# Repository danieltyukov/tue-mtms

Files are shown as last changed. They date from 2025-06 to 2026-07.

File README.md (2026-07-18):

<p align="center">
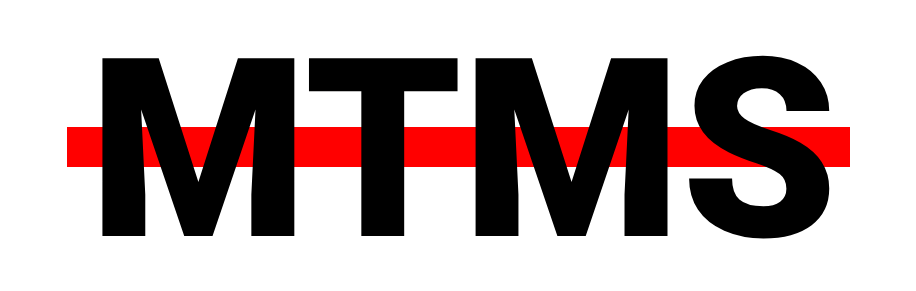
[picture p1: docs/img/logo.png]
  
</p>

<p align="center">
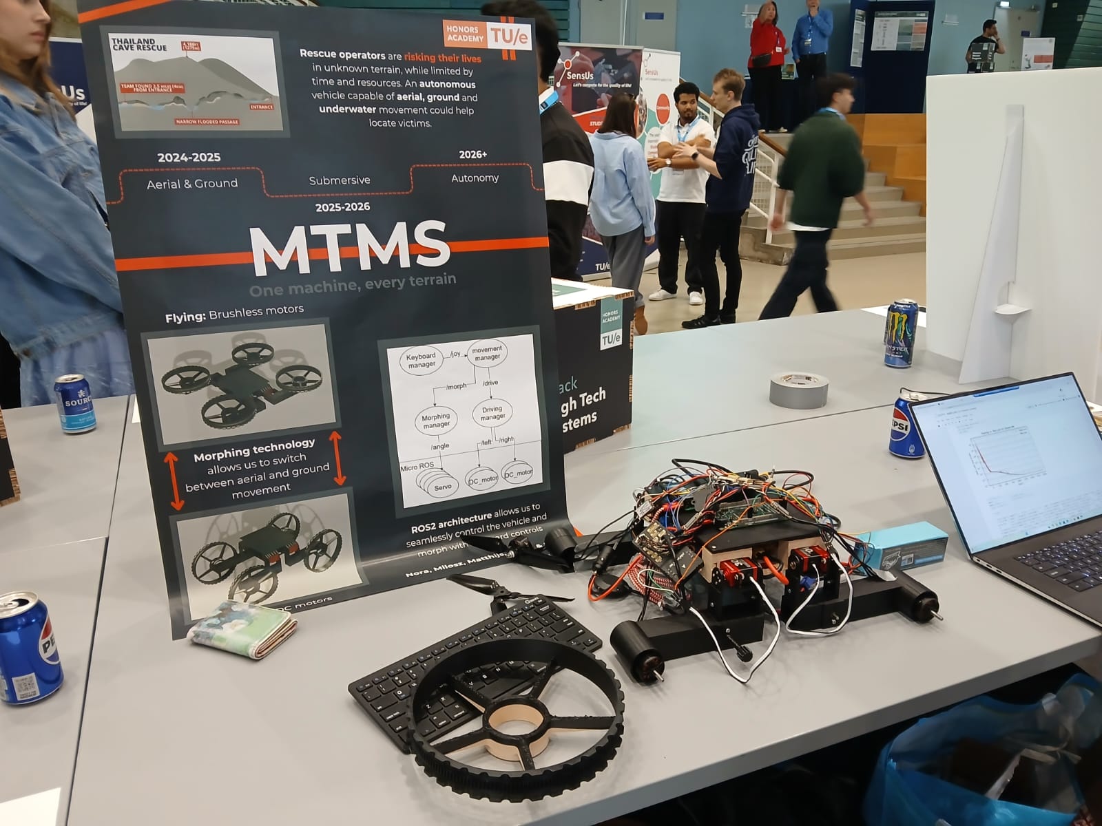
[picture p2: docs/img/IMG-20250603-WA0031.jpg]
  
</p>

# Multi-Terrain Mobility System (MTMS)

MTMS is a land and air convertible robot built for the TU/e Honors Academy High Tech Systems track (Year 2, 2024-2025). The robot carries four legs, each holding a combined wheel and propeller. It drives on the ground like a rover, then physically rotates each leg by 90 degrees to point the propellers upward and take off as a quadcopter. The long-term motivation is a rescue vehicle that can reach victims across terrain that a single ground or aerial vehicle cannot cover on its own.

Over the year the team designed and built a working prototype: the mechanical chassis and morphing mechanism, a custom power distribution board, and a ROS 2 software stack that lets an operator drive the robot, trigger the transformation, and fly it from a single keyboard.

## Prototype

The mechanical design centers on a stack of plates that house the battery, power distribution, and compute, with four legs that each carry a wheel-propeller assembly. The two states below are the same robot: wheels down for driving, and rotated for flight.

<p align="center">
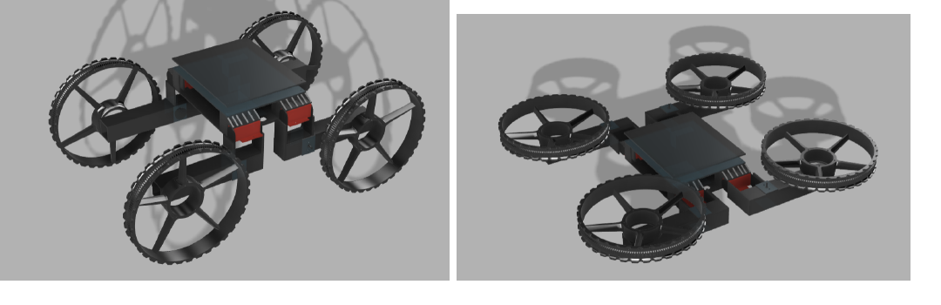
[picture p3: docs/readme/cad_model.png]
  
</p>

## Software architecture

The control software runs on ROS 2 (Jazzy) on a Raspberry Pi 5, with a micro-ROS firmware layer on an Arduino Due that drives the motors and servos. The nodes form a small pipeline from keyboard input down to hardware:

- `keyboard` and `keyboard_to_joy` capture keypresses through SDL and turn them into a `sensor_msgs/Joy` message. W/S and A/D map to the throttle and steering axes, Space is a boost button, and Q requests a mode change.
- `movement_manager` subscribes to `/joy` and routes input to either the `/drive` or `/fly` topic depending on the current mode. Pressing Q sends a `MorphAction` goal, with debouncing so a single press does not trigger repeated transitions.
- `drive_manager` converts the joystick axes into tank-style left and right motor commands and publishes them as PWM values on `/drive_left` and `/drive_right`.
- `morph_manager` is the `MorphAction` server. It sweeps the leg servos between the drive and fly positions in small steps through a `SetAngle` service and reports transition progress as feedback.
- The Arduino Due firmware (`code/Servo_sweeping`, PlatformIO) is a micro-ROS node. It subscribes to `/drive_left` and `/drive_right` to drive four DC motors and hosts the `servo_service` that rotates the four leg servos.

`movement_msgs` defines the custom `MorphAction` action and `SetAngle` service that tie these nodes together.

## Repository structure

```
code/ros_ws/            ROS 2 workspace
  src/movement_manager/  movement, drive and morph manager nodes
  src/movement_msgs/     MorphAction action and SetAngle service
  src/keyboard_controls/ keyboard capture and keyboard-to-joy conversion
  src/launch_mtms/       top-level launch files
code/Servo_sweeping/    micro-ROS firmware for the Arduino Due (PlatformIO)
code/startup.sh         boot script, paired with start_robot.service
BMS_schematic/          battery management KiCad project
mechanical/             CAD designs and STL exports
docs/                   logo, Gantt planning, report figures
Honors_report_2025.pdf  full project report
```

## Running it

Build the workspace and launch the stack on the robot:

```bash
cd code/ros_ws
colcon build
source install/setup.bash

# start the micro-ROS agent so the Arduino Due can join the ROS 2 graph
ros2 run micro_ros_agent micro_ros_agent serial --dev /dev/ttyACM0

# start the managers and keyboard control
ros2 launch launch_mtms launch_mtms_launch.py
```

The keyboard node opens a small window that must stay focused to receive input. On the robot itself the same flow is wired into `code/startup.sh` and a `start_robot.service` unit so everything comes up on boot.

## Hardware

- Raspberry Pi 5 as the main computer running the ROS 2 stack
- Arduino Due running the micro-ROS firmware for motor and servo control
- Pixhawk 6C flight controller for the aerial mode
- Brushless motors and propellers for flight, DC motors and servos for driving and morphing
- 22.2V 4000mAh 6S LiPo battery
- Custom power distribution PCB (KiCad) with XT60 input and multiple XT30 outputs

## Technologies

ROS 2 Jazzy, Python, micro-ROS, C++ (Arduino / PlatformIO), KiCad, CAD.

## Planning

Progress was tracked with Gantt charts that were revised as component deliveries and priorities shifted. The full schedule and milestones are in [docs/gantt_chart.svg](docs/gantt_chart.svg).

## Contributors

Team MTMS

- Alex Ceano Vivas i Camacho (coach, Honors High Tech Systems track)
- Nora Balje
- Daniel Tyukov
- Ismail Hassaballa
- Milosz Janewski
- Matthijs Smulders

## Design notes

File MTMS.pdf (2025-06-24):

## MTMS: Multi-Terrain Mobility Systems

## Project proposal

High tech systems

Nora Balje´
Milosz Janewski
Daniel Tyukov
Matthijs Smulders
Ismail Hassaballa

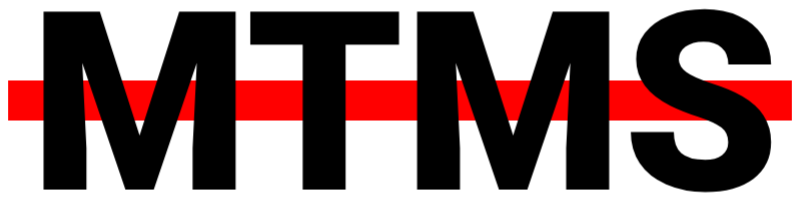
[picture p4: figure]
Date: June 24, 2025

High tech systems: MTMS Project Proposal

## Contents

Abstract | 3
Description | 3
Workpackages and timeline | 4
Impact | 5
Demo Day package | 5
Equipment and Budget | 6

## Abstract

The MTMS (Multi-Terrain Mobility Systems) project proposal outlines the potential development of a multi-terrain robot capable of transitioning between ground, aerial and water based modes. Existing research, combining 2 out of 3 of the previously mentioned modes, showcases that creating such a system would be possible, however combining all 3 has yet to be done. The primary objective for the coming year of the project is to build a functional prototype running on Robot Operating System 2 with integrated wheels and rotors, enabling manual control and basic navigation for ground and aerial based modes. Over the course of the year, the focus will be on hardware assembly, system integration, and testing of the robot’s hybrid mobility capabilities. In the following years, further development will focus on integrating the water based mode, creating a fully autonomous navigation functionality, obstacle avoidance, and terrain mapping. The overall budget for this initial phase is approximately two thousand six hundred euros.

## Description

For our project, we want to build a Multi-terrain mobility system, where we will start with ground and aerial mobility for this current year. Water based movement and autonomous control will follow in future years. The ground based movement will take the form of a remote control car, then it will be able to fold its wheels below its body to morph into a type of drone, allowing for aerial movement. We are going to depict how we will design such a system, what software and hardware we will need, what the timeline for building said system will be and how we can extend upon it in future years.

Design

We plan to take most of our inspiration from the M4 robot built by CalTech [1] and the Flying STAR built by Nir Meiri and David Zarrouk [2]. Both these robots have propellors and wheels on the end of their arms and rely on moving these arms down to move between mode of transportation. We want to implement a similar approach, and challenge ourselves to include a joint in the arms for extra ground and air mobility with morphing capabilities. We can build upon research for wheeled quadrupedal such as Bjelonic, M. et al’s research [3].

Software

We chose to use ROS2 (Robot operating System 2) software as it provides a robust, widely adopted framework for robotic development, with extensive community support. Additionally, we opted for ROS2 instead of ROS1, due to improved architecture and speed of the framework. Hence, compatibility with ROS2 was a main factor taken into account when choosing our hardware components.

Hardware

Because we are designing a robot with non-standard functionality, obtaining parts off the shelf can be difficult, particularly for connecting all the electronics together. This is why we plan to 3D print many parts ourselves, which provides the flexibility needed for our design specifications. Within the team, we are currently discussing the use of Fusion 360 or Onshape for designing these parts, as both programs offer similar tools suited to our requirements.

However, this approach presents challenges for future multi-mobility in water. While 3D printing offers quick prototyping, the materials (PLA) are not reliably waterproof. Additionally, isolating electronics from water effectively and ensuring buoyancy requires specific materials and design adjustments. While we are not focusing on this aspect in the current project phase, our long-term goal includes research in waterproofing, buoyancy, and electronics protection. This foundational research aims to eventually make the system rainproof and eventually submersible.

Flight Controller and Power Electronics

For the flight controller, we plan to use the Pixhawk 6C, due to its many capabilities and native ROS2 compatibility. The PX4 provides us with a well-supported platform for handling aerial navigation, allowing integration with the robot’s multiple sensors and actuators. We can use tools like Ardupilot which enables us to test and fine-tune our system across different flight modes.

On the power electronics side, we’re assembling a power distribution system internally inside the system. This includes a 4S 4000Mah battery with step-down buck converters to maintain specific voltage requirements across the system. To keep the mechanical design of the system adaptable, we’ll incorporate a basic PCB with inputs and outputs for wire connections (a basic power distribution board with outsourced components). This will centralizes wiring but also simplifies adjustments to the setup.

To track power usage, we will integrate a current and voltage sensor within the power electronics system. This will allow us to monitor consumption in real-time.

While autonomy is limited, this initial phase of the project is focused primarily on predefined movement sequences in ROS2. We aim to research the potential for greater autonomy by using sensor data for future, including obstacle avoidance via infrared sensors. Currently, the system will be controlled manually, with specific automatic reactions.

Component | Quantity | Voltage (V) | Current (A) | Power (W)
Hip Servos Wheel Motors Propeller ESCs Main Controller Flight Controller | 8 4 4 1 1 | 7.4 12 12 5 5 | 3.0 1.5 4.0 0.5 0.4 | 177.6 72.0 192.0 2.5 2.0
Total | | | | 446.1

Table 1: Estimated Power Consumption of Key Components

Future Development

As mentioned the focus for this year will be on ground and aerial control, however, eventually we wish to create an all-terrain vehicle that can survive any circumstances. So one clear future development would be implementing mobility in the water. After that, we want to slowly progress to autonomy within the robot, such that even without human control it can reach its destination. This would obviously require advanced navigation, obstacle avoidance, and autonomous mission planning, but also terrain detection and knowing when to morph, all powered by ROS2 algorithms. We will discuss how the current sensor data and manual control operations serve as the foundation for the future autonomous capabilities of the robot.

## Workpackages and timeline

Nov | Dec | Jan | Feb | Mar | Apr | May | Jun
Midterm Review (Feb 4) | Final Demo (Jun 3)
Structure & Design | ROS Development

Module Testing
Integration Testing

This timeline outlines the planned phases and milestones for the MTMS project. After receiving approval for our plan on November 15, we plan to order all necessary components, which according to their checked lead times should arrive by the end of November. Having acquired all components we can dedicate December to assembling the robot, including designing and 3D printing custom parts as needed. From January to April, we’ll work on ROS2 development and control implementation. Where January the focus will be on ground based control, February the focus will be on morphing and in March the focus will be on Aerial control. In April and May, individual modules will undergo testing, followed by full integration testing by mid-May. Key milestones include the midterm review on February 4 and the final demonstration on June 3.

## Impact

Our MTMS is set to redefine exploration of unknown or hazardous terrains. Unlike current solutions that are limited to only one or two specific terrain types, such as ground and aerial or aerial and water, the end goal for our MTMS is that it can navigate and adapt to three terrain types: ground, aerial and water. This versatility could revolutionize exploration in locations where traditional methods are ineffective or unsafe, such as disaster sites, alien landscapes, or varied terrains that demand adaptability.
The impact of our system lies in its accessibility and efficiency, especially compared to high-budget, long-term projects like Caltech’s M4 [1]. By prioritizing a leaner budget and a short development timeline, MTMS could make advanced terrain mobility more achievable for a wider range of applications. We will also focus on a smaller scale testing environment by developing the system in ROS2, which enhances the research value. While water traversal is outside this year’s scope, we’ll start researching the possibilities for future development. Ultimately, our project could open up the road to more versatile multi-terrain traversal which is more financial accessible and contributes to further research in this field.

## Demo Day package

On the final presentation day, we will demonstrate the multi-terrain robot prototype that we developed over the course of the year. The goal of this demo is to showcase the robot’s dual mobility capabilities, transitioning smoothly between ground and aerial modes, and moving in each mode, while being manually controlled via a ROS2 interface.

Key Objectives for Demo day

- Manual Control via ROS2 Interface: We will demonstrate the robot’s ability to be controlled manually through a ROS2-based interface. Attendees will be able to see how we utilize ROS2 to operate both the wheeled and rotor-based mobility systems, highlighting the integration between hardware and software.
- Ground Mobility: The robot’s wheeled mobility system will be showcased by navigating through an obstacle course, demonstrating its ability to handle different types of terrain, such as uneven surfaces and ramps.
- Aerial Mobility: Following the ground demonstration, we will showcase how the robot switches to its aerial mode. However as it is not feasible to fly the robot during the demo day itself this skill will be presented in a pre-recorded video. Here we will showcase stable flight control.

Midterm Demo Day

On the midterm demo day we wish to showcase the hardware design of the robot and its ability to move on the ground. We aim to showcase our progress in both the hardware and software component by presenting our moving vehicle. The complex movements such as morphing and flying will not be showcased here as we do not aim to have these implemented by the midterm presentation.

## Equipment and Budget

The costs of all necessary hardware components for this project will come to a total of C2594.65. The breakdown of these costs is depicted in the table below. Alongside these hardware costs there are theoretical labor costs that come along with creating such a project. To realize this project we will need a team of 5 people, who will work on this project approximately 6 hours a week for the next 33 weeks. Assuming a pay of C15 an hour this will bring in an additional cost of C14850 in labor. However, due to the nature of our project we will not count labor costs
towards the final budget.
Component | Description | Price | Supplier | Delivery time
Main Computer | UP Xtreme i14 | C967 | Up squared/Mouser | Email inquiry
Flight controller | Pixhawk 6C | C220 | Holybro | 1 week
Secondary Computer | Raspberry Pi 5 | C94.90 | reichelt | 3 days
Microcontroller | Raspberry Pi pico | C8.5 | Tinytronics | 3 days
Lidar sensor | For scanning area | C124 | Generation robots | 3 days
GPS Module | M10 | C80 | Holybro | 1 week
Telemetry Radio | 433MHz | C100 | Holybro | 1 week
3x Batteries | To power the system | C290.37 | Racedayquads | 3 days
4x wheel | To enable driving | C28 | Amazon | 3 days
4x 3MR Series - 3-Blade 8x4.1 Propeller | To enable flight | C20 | masterairscrew | 2 weeks
4x DC motor | To move the wheels | C74,04 | Mouser Electronics | 5 days
2x motor driver board | to control the motors | C33 | Tiny tronics | 1 day
4x EMAX Bullet Series 35A 3-6S ESC | To control and adjust power for the
| brushless motors | C80 | Emax | 1 week
4x Pro Series 2812 Brushless Motor | To move the propellors | C120 | Emax | 1 week
8x Servo (180°) | To enable the 2 joints per leg | C176 | TinyTronics | 1 day
2x Mini 12V 4”Stroke Electric Linear Actuator | To enable shifting between flight and
| driving | C60 | Amazon | 1 week
3x Camera’s (120°) | To enable the person in control to
| see around vehicle | C91,28 | Adafruit | 4 days
2 kg PLA filament | For 3D prining custom parts for as- sembly and frame | C59,80 | TinyTronics | 1 day
Miscellaneous | Additional wiring, connectors and assembly parts | C90 | TinyTronics, etc | Depends on parts
Total | - | C2720.00 | - | -

Table 2: Component and Budget List for Multi-Terrain Robot

## References

[1] Sihite, E., Kalantari, A., Nemovi, R. et al. Multi-Modal Mobility Morphobot (M4) with appendage repurposing for locomotion plasticity enhancement. Nat Commun 14, 3323 (2023). https://doi.org/10.1038/s41467-023-39018-y
[2] N. Meiri and D. Zarrouk, Flying STAR, a Hybrid Crawling and Flying Sprawl Tuned Robot, 2019 International Conference on Robotics and Automation (ICRA), Montreal, QC, Canada, 2019, pp. 5302-5308, doi: 10.1109/I-CRA.2019.8794260.
[3] M. Bjelonic et al., Keep rollin’—whole-body motion control and planning for wheeled quadrupedal robots, IEEE Robotics and Automation Letters, vol. 4, no. 2, pp. 2116–2123, Apr. 2019. Available: https://arxiv.org/pdf/1809.03557

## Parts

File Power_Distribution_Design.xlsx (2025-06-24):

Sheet: Power Table
Component | Voltage | Current (A) | Quantity | Power Domain | Power (W) | Energy Share (Wh)
Brushless Motor + ESC | 11.1–22.2V | 60 | 4 | Primary | 1332 | 22.2
Pixhawk 6C System | 5V | 1 | 1 | Primary | 5 | 0.08333333333
Servo | 8.4V | 18.4 | 4 | Secondary | 154.56 | 2.576
RPi 5 | 5.1V | 5 | 1 | Secondary | 25.5 | 0.425
Linear Actuator | 12V | 1.2 | 2 | Secondary | 14.4 | 0.24
Arduino Due | 7–20V | 0.2 | 1 | Secondary | 4 | 0.06666666667
DC Motor | 12V | 2.8 | 4 | Secondary | 33.6 | 0.56
Lidar | 5V | 0.26 | 1 | Secondary | 1.3 | 0.02166666667

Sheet: Summary
Total Battery Voltage (V) | Battery Capacity (Ah) | Battery Energy (Wh) | Total Power Draw (W) | Primary System Power (W) | Secondary System Power (W)
22.2 | 4 | 88.8 | 1570.36 | 1337 | 233.36

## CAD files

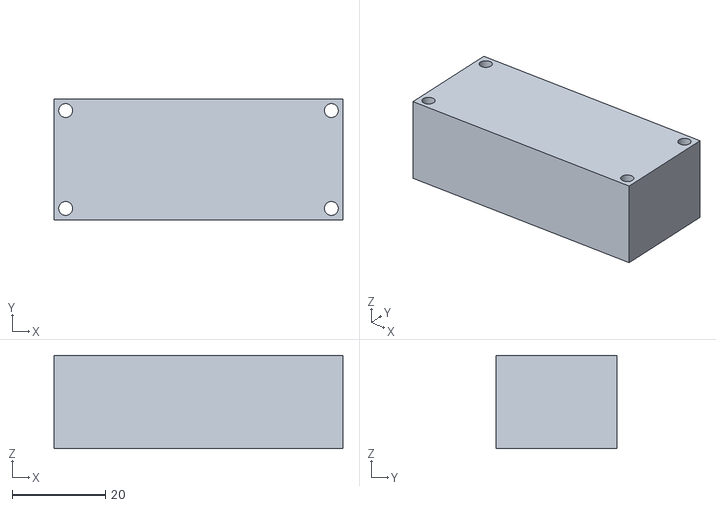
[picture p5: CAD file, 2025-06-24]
mechanical/CAD_designs/Buck+converter.stl
62.0 x 26.0 x 20.0

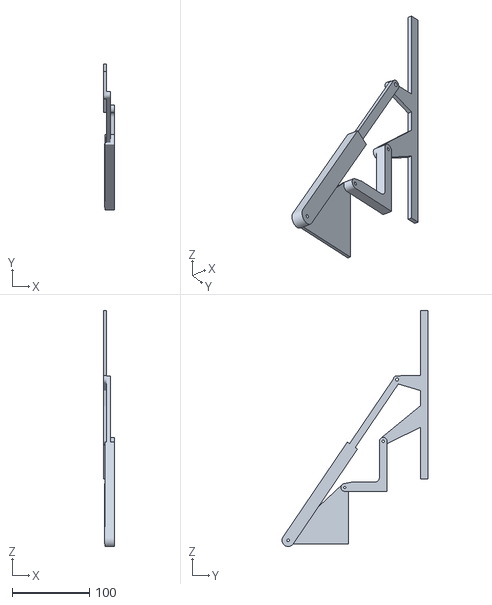
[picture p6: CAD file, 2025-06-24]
mechanical/MTMS-Transform-Mechanism-V1.stl
14.0 x 189.5 x 306.4

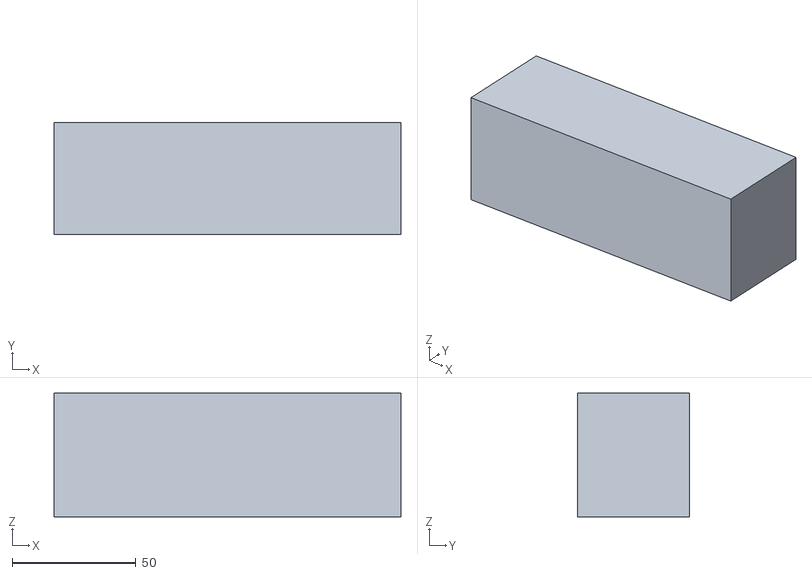
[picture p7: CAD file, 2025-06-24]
mechanical/CAD_designs/LiPo+(approximatedd+size).stl
140.0 x 45.0 x 50.0

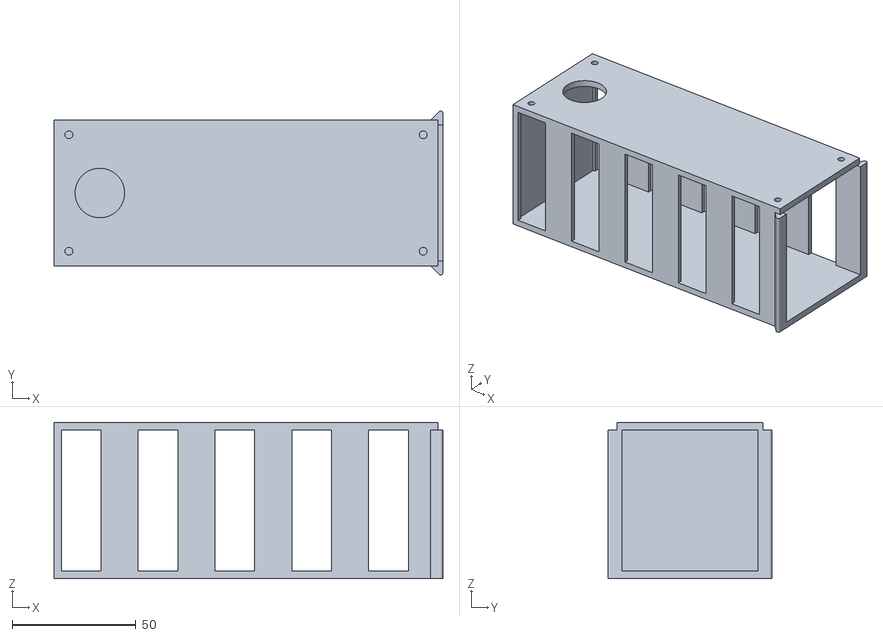
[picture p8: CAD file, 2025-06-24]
mechanical/CAD_designs/Battery+cover (1).stl
157.0 x 66.2 x 63.0

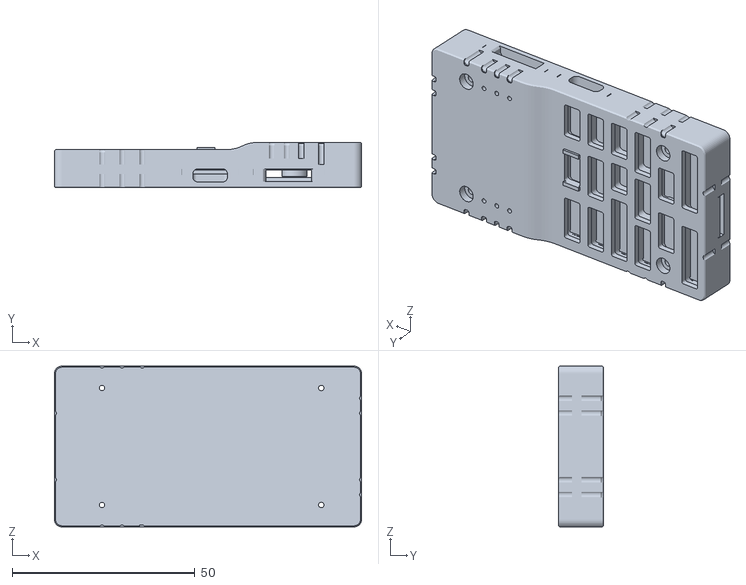
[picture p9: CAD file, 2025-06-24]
mechanical/CAD_designs/Pixhawk6C-3D-CAD.stl
84.0 x 12.4 x 44.0

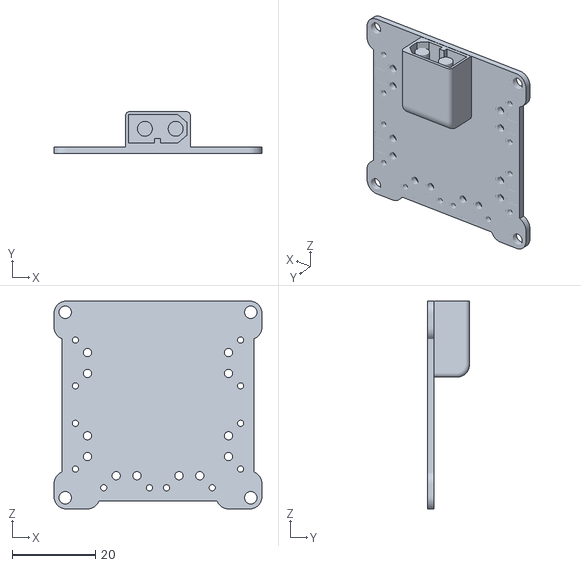
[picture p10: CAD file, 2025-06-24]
mechanical/CAD_designs/Power+distribution.stl
50.0 x 10.1 x 50.0

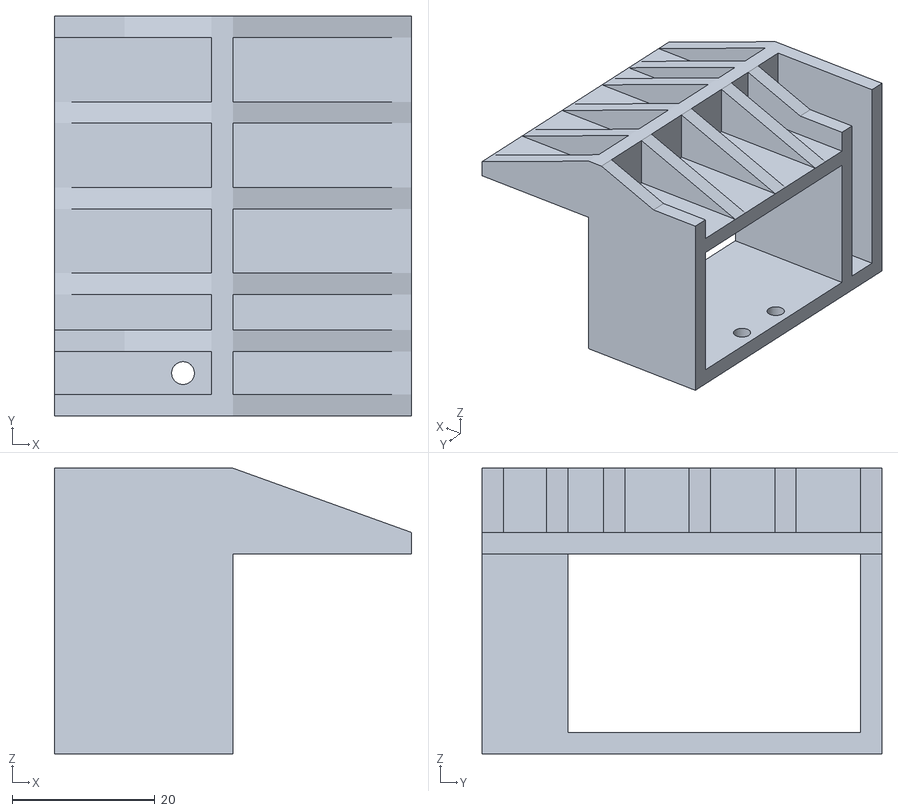
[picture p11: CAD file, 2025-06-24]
mechanical/CAD_designs/Single+holder+for+transformation+motor (2).stl
50.0 x 56.0 x 40.0

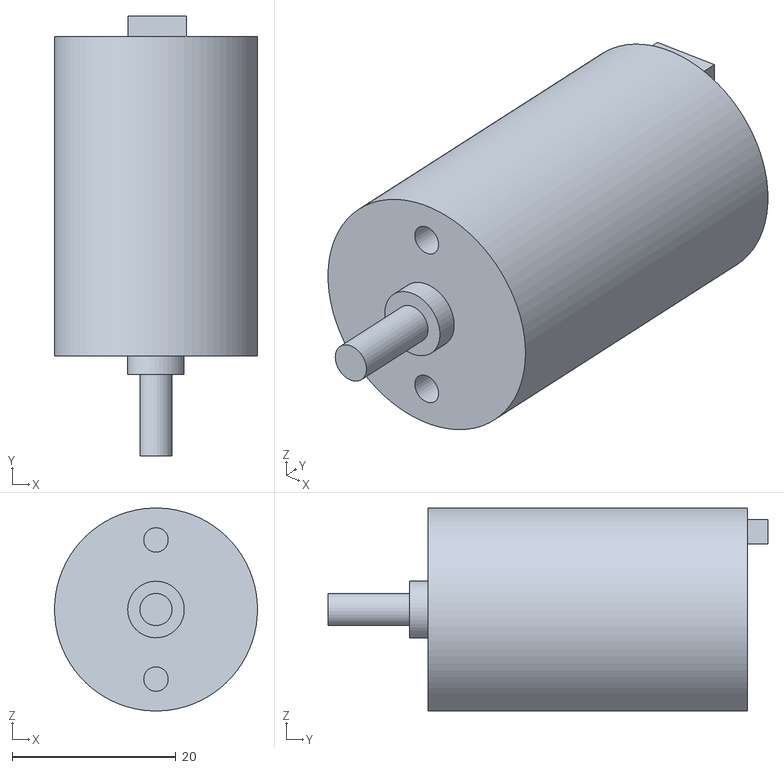
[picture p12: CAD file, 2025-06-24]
mechanical/CAD_designs/DC+motor+(measured).stl
24.8 x 53.7 x 24.8

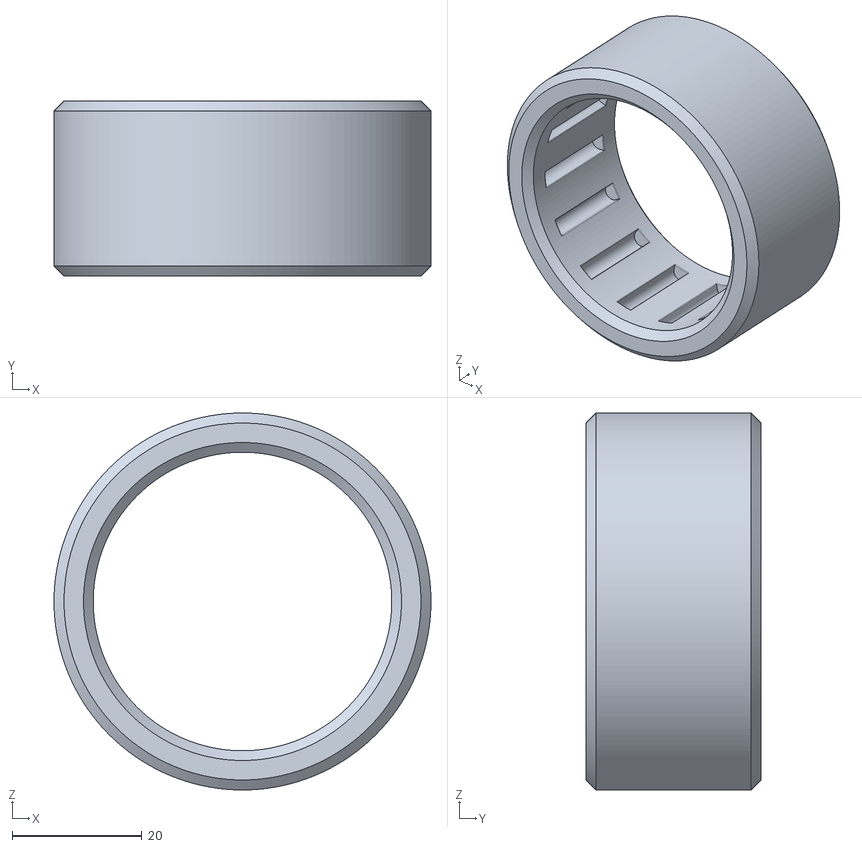
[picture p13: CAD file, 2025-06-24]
mechanical/CAD_designs/bearing (1).stl
58.1 x 27.0 x 58.1

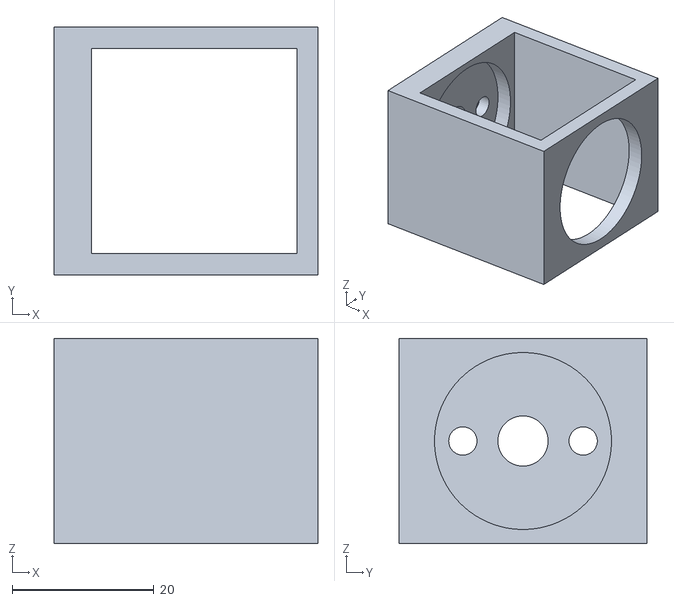
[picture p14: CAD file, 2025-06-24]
mechanical/CAD_designs/DC+motor+mount+in+leg (2).stl
37.3 x 35.0 x 29.0

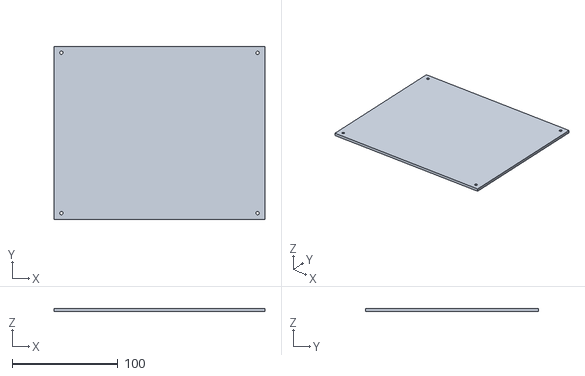
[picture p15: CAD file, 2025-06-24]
mechanical/CAD_designs/Top+plate (1).stl
200.0 x 164.0 x 3.00

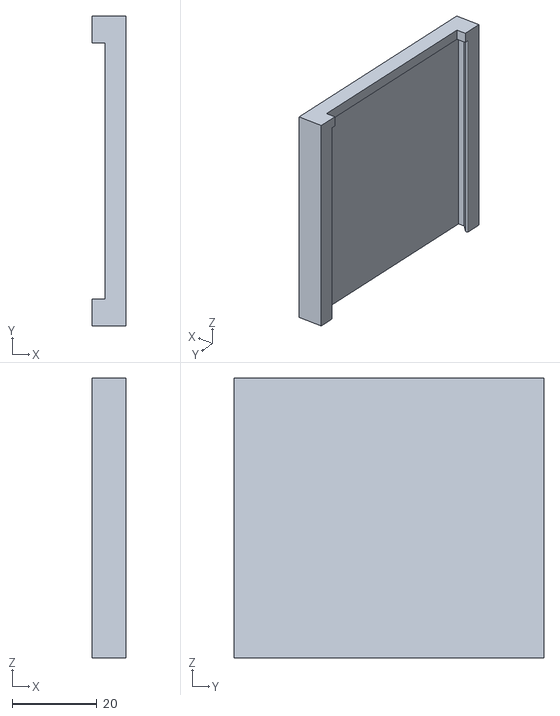
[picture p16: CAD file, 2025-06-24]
mechanical/CAD_designs/Closing+for+battery+cover (1).stl
8.00 x 73.0 x 66.0

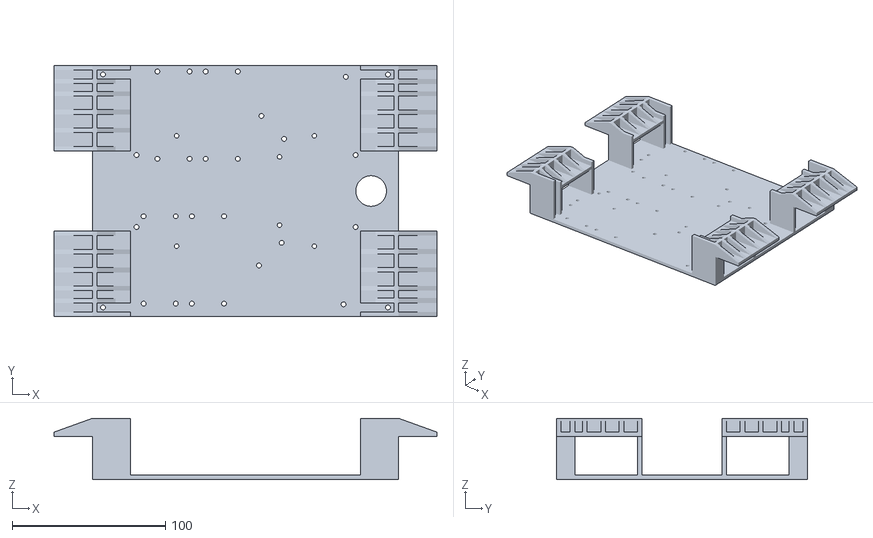
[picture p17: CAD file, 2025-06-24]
mechanical/CAD_designs/Bottom+Plate (7).stl
250.0 x 164.1 x 40.0

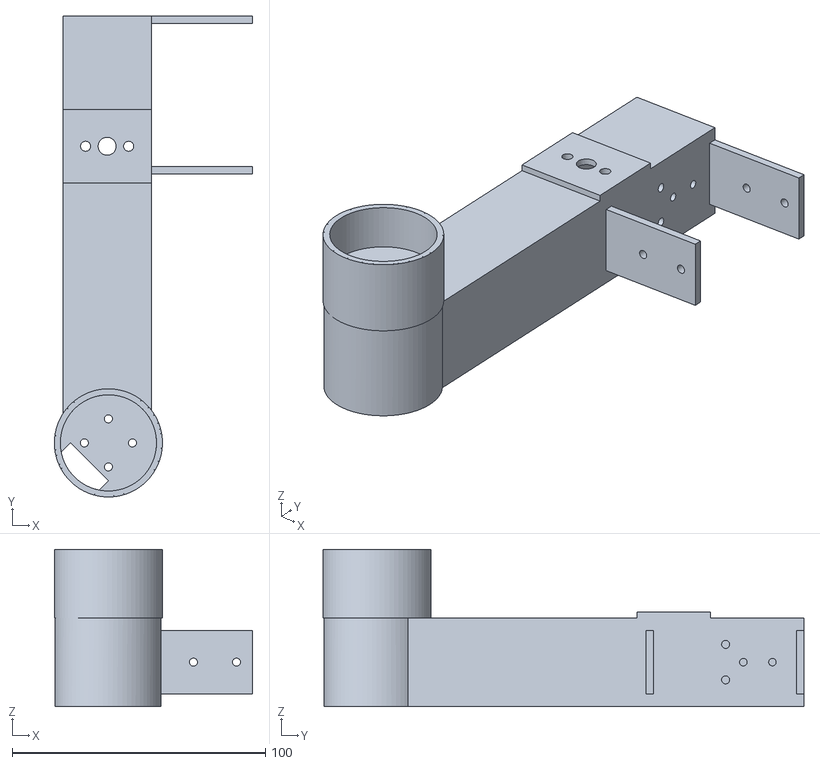
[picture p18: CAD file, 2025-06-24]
mechanical/CAD_designs/Leg (3).stl
78.4 x 190.0 x 62.0

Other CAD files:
mechanical/CAD_designs/wheel_matched_to_size (2).stl
mechanical/CAD_designs/Chassis+(for+now).stl
mechanical/CAD_designs/Middle+plate (1).stl
mechanical/CAD_designs/Raspberry+Pi+5.stl
mechanical/CAD_designs/Battery+plate (1).stl
mechanical/CAD_designs/Leg+servo+-+roughly+how+much+space+it+will+take+on+the+platform+(so+excluding+what+is+outside).stl
mechanical/CAD_designs/Plates+-+connected.stl
mechanical/CAD_designs/Porpeller+holder+for+leg (2).stl

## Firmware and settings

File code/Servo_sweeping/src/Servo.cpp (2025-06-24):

#include <Arduino.h>
#include <micro_ros_platformio.h>

#include <Servo.h>
#include <rcl/rcl.h>
#include <rclc/executor.h>
#include <rclc/rclc.h>

#include <movement_msgs/srv/set_angle.h>
#include <std_msgs/msg/float32.h>
#include <std_msgs/msg/int32.h>
#include <std_srvs/srv/set_bool.h>

#include <rosidl_runtime_c/string_functions.h>

rcl_service_t service;
rcl_publisher_t publisher;

rcl_subscription_t right_motor;
rcl_subscription_t left_motor;

std_msgs__msg__Float32 right_msg;
std_msgs__msg__Float32 left_msg;

rclc_executor_t executor;
rcl_node_t node;

rcl_allocator_t allocator;
rclc_support_t support;

// std_srvs__srv__SetBool_Request req;
// std_srvs__srv__SetBool_Response res;

movement_msgs__srv__SetAngle_Request req;
movement_msgs__srv__SetAngle_Response res;

Servo servo1;
Servo servo2;
Servo servo3;
Servo servo4;

int init_servo_angle_left = 0;
int init_servo_angle_right = 180;



int SERVO1_PIN = 53;
int SERVO2_PIN = 51;
int SERVO3_PIN = 49;
int SERVO4_PIN = 47;

// Right Motors
int MOTOR1_PWM_PIN = 2;
int MOTOR1_DIR_PIN = 6;
int MOTOR1_FG_PIN = 11;

int MOTOR2_PWM_PIN = 3;
int MOTOR2_DIR_PIN = 7;
int MOTOR2_FG_PIN = 10;

// Left Motors
int MOTOR3_PWM_PIN = 4;
int MOTOR3_DIR_PIN = 8;
int MOTOR3_FG_PIN = 12;
    
int MOTOR4_PWM_PIN = 5;
int MOTOR4_DIR_PIN = 9;
int MOTOR4_FG_PIN = 13;

void right_callback(const void *msgin) {
    // digitalWrite(12, HIGH);
    // analogWrite(A5, 0);
    const std_msgs__msg__Float32 *msg = (const std_msgs__msg__Float32 *)msgin;
    float speed = msg->data;

    if (speed >= 0) {
        digitalWrite(MOTOR1_DIR_PIN, LOW);
        digitalWrite(MOTOR2_DIR_PIN, LOW);
    } else {
        digitalWrite(MOTOR1_DIR_PIN, HIGH);
        digitalWrite(MOTOR2_DIR_PIN, HIGH);
    }

    analogWrite(MOTOR1_PWM_PIN, 255 - abs(speed));
    analogWrite(MOTOR2_PWM_PIN, 255 - abs(speed));
}

void left_callback(const void *msgin) {

    const std_msgs__msg__Float32 *msg = (const std_msgs__msg__Float32 *)msgin;
    float speed = msg->data;

    if (speed >= 0) {
        digitalWrite(MOTOR3_DIR_PIN, LOW);
        digitalWrite(MOTOR4_DIR_PIN, LOW);
    } else {
        digitalWrite(MOTOR3_DIR_PIN, HIGH);
        digitalWrite(MOTOR4_DIR_PIN, HIGH);
    }

    analogWrite(MOTOR3_PWM_PIN, 255 - abs(speed));
    analogWrite(MOTOR4_PWM_PIN, 255 - abs(speed));
}

void service_callback(const void *request_msg, void *response_msg) {
    const movement_msgs__srv__SetAngle_Request *req_in =
        (const movement_msgs__srv__SetAngle_Request *)request_msg;
    movement_msgs__srv__SetAngle_Response *res_out =
        (movement_msgs__srv__SetAngle_Response *)response_msg;

    int angle = req_in->angle;

    if (angle >= 0 && angle <= 180) {
        servo1.write(angle);
        servo2.write(angle);
        servo3.write(180 - angle);
        servo4.write(180 - angle);
        delay(1000);
        res_out->success = true;
        rosidl_runtime_c__String__assign(&res_out->message, "Moved to angle");
    } else {
        res_out->success = false;
        rosidl_runtime_c__String__assign(&res_out->message,
                                         "Angle out of range");
    }
}

void setup() {
    Serial.begin(115200);
    delay(2000);

    // Attach servos
    servo1.attach(SERVO1_PIN);
    servo2.attach(SERVO2_PIN);
    servo3.attach(SERVO3_PIN);
    servo4.attach(SERVO4_PIN);

    // Setup dc motors
    // Set pinModes
    pinMode(MOTOR1_PWM_PIN, OUTPUT);
    pinMode(MOTOR2_PWM_PIN, OUTPUT);
    pinMode(MOTOR3_PWM_PIN, OUTPUT);
    pinMode(MOTOR4_PWM_PIN, OUTPUT);

    pinMode(MOTOR1_FG_PIN, INPUT_PULLUP);
    pinMode(MOTOR2_FG_PIN, INPUT_PULLUP);
    pinMode(MOTOR3_FG_PIN, INPUT_PULLUP);
    pinMode(MOTOR4_FG_PIN, INPUT_PULLUP);

    pinMode(MOTOR1_DIR_PIN, OUTPUT);
    pinMode(MOTOR2_DIR_PIN, OUTPUT);
    pinMode(MOTOR3_DIR_PIN, OUTPUT);
    pinMode(MOTOR4_DIR_PIN, OUTPUT);

    // Initialize motors and servos to correct positions
    analogWriteResolution(8);
    analogWrite(MOTOR1_PWM_PIN, 255);
    analogWrite(MOTOR2_PWM_PIN, 255);
    analogWrite(MOTOR3_PWM_PIN, 255);
    analogWrite(MOTOR4_PWM_PIN, 255);

    digitalWrite(MOTOR1_DIR_PIN, LOW);
    digitalWrite(MOTOR2_DIR_PIN, LOW);
    digitalWrite(MOTOR3_DIR_PIN, LOW);
    digitalWrite(MOTOR4_DIR_PIN, LOW);

    servo1.write(init_servo_angle_left);
    servo2.write(init_servo_angle_left);
    servo3.write(init_servo_angle_right);
    servo4.write(init_servo_angle_right);

    std_msgs__msg__Float32__init(&right_msg);
    std_msgs__msg__Float32__init(&left_msg);

    // Setup Micro-ROS
    set_microros_serial_transports(Serial);

    allocator = rcl_get_default_allocator();

    rclc_support_init(&support, 0, NULL, &allocator);
    rclc_node_init_default(&node, "micro_ros_node", "", &support);

    // Initialize subscriptions and services
    rclc_subscription_init_default(
        &right_motor, &node,
        ROSIDL_GET_MSG_TYPE_SUPPORT(std_msgs, msg, Float32), "drive_right");
    rclc_subscription_init_default(
        &left_motor, &node, ROSIDL_GET_MSG_TYPE_SUPPORT(std_msgs, msg, Float32),
        "drive_left");

    rclc_service_init_default(
        &service, &node,
        ROSIDL_GET_SRV_TYPE_SUPPORT(movement_msgs, srv, SetAngle),
        "servo_service");

    // Initialize executor and allocate subs and srvs to executor
    rclc_executor_init(&executor, &support.context, 3, &allocator);
    rclc_executor_add_subscription(&executor, &right_motor, &right_msg,
                                   &right_callback, ON_NEW_DATA);
    rclc_executor_add_subscription(&executor, &left_motor, &left_msg,
                                   &left_callback, ON_NEW_DATA);
    rclc_executor_add_service(&executor, &service, &req, &res,
                              service_callback);
}

void loop() { rclc_executor_spin_some(&executor, RCL_MS_TO_NS(100)); }
